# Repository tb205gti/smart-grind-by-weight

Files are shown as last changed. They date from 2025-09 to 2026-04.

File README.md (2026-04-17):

# Smart Grind-by-Weight

**Turn any grinder into a precision smart grind-by-weight system**

<table>
<tr>
<td width="50%">

https://github.com/user-attachments/assets/e20ce3e2-417e-4a3b-bb48-05591fce9418

</td>
<td width="50%">

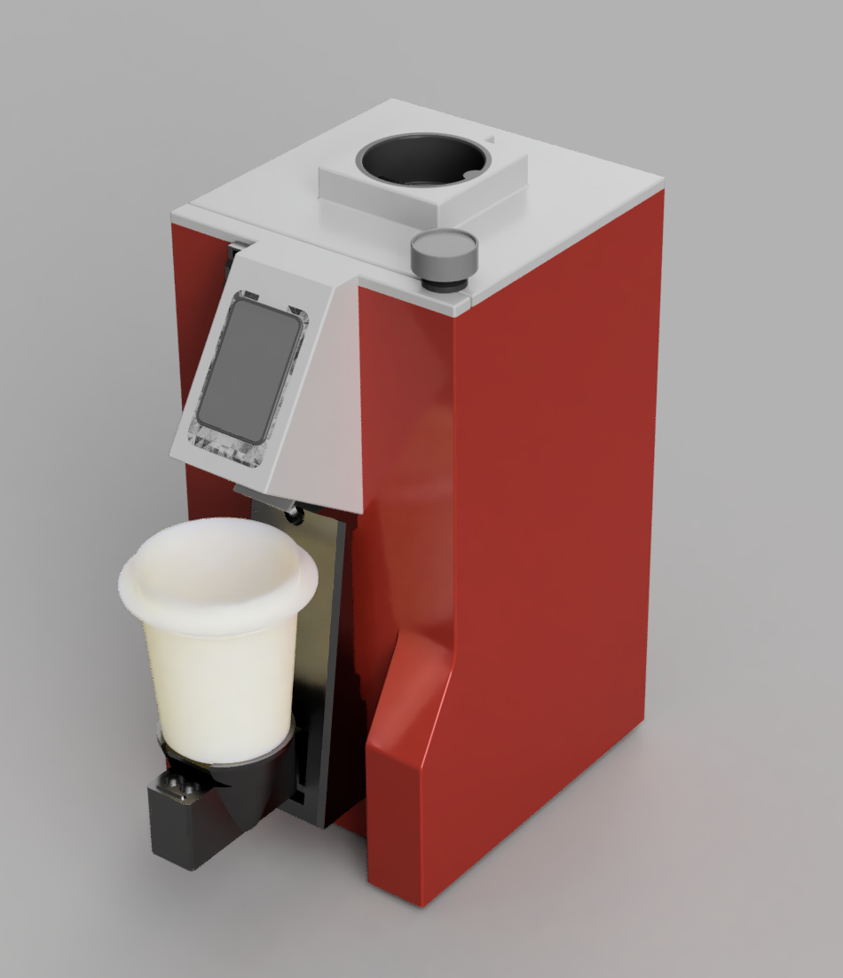
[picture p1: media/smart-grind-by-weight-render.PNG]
Smart Grind-by-Weight Modification
[](media/smart-grind-by-weight-render.PNG)

</td>
</tr>
</table>

> **⚠️ Newly Released Mod - Buyer Beware!**  
> This is a **recently released modification project** that transforms grinders into smart grind-by-weight systems. While functional and free/open source, it's should be considered an **experimental mod** that requires technical skill to build and may have rough edges. **Build at your own risk** !

The Smart Grind-by-Weight is a user-friendly, touch interface-driven, highly accurate open source grinder modification that can transforms any grinder (with a accesable motor relay) into an intelligent grind-by-weight system. Originally developed for the Eureka Mignon Specialita, the system can be easily adapted for other grinders.

**The concept is simple:** Perform a "brain swap" on your grinder. Replace the original controller with our intelligent ESP32-S3 controller and add a precision load cell to the mix.

**Upgrade cost:** €30-40 in parts  
**Target accuracy:** ±0.03g tolerance  
**No regrets**: No permanent modifications, and original grind-by-time mode is also available

---

## ✨ Features

- **User-friendly interface** with 3 profiles: Single, Double, Custom
- **Beautiful display** with simple graphics or detailed charts (easily switchable)
- **High accuracy**: ±0.03g error tolerance  
- **Zero-shot learning**: Algorithm adapts instantly to any grind size, bean setting, humidity etc. without manual tuning
- **Original timed run preserved** – there is a setting to enable the original Grind-By-Time mode
- **BLE OTA updates** for firmware
- **Advanced analytics** using BLE data transfer and Python Streamlit reports
- **For Eureka**: No permanent modifications needed - just swap the screen and add 3D printed parts

---

## 🧠 Intelligent Grinding Algorithm

Our predictive grinding system uses a zero-shot learning approach that adapts to any conditions:

```mermaid
flowchart LR
  start((Start Grind)) --> T[TARING]
  T --> E[PREDICTIVE<br/>learn latency & flow_rate<br/>compute motor_stop_target_weight]
  E --> S[SETTLING]
  S --> P[PULSE<br/>bounded pulse using effective_flow_rate]
  P -->|abs_error <= tolerance OR error < 0 OR pulses >= max| C[COMPLETED]
  P -->|needs more| S
```

**Key Innovation:** The algorithm learns grind latency and flow rate in real-time, then uses predictive control to stop just before the target weight, followed by precision pulses to reach exact accuracy. No manual tuning required.

---

## 🚀 Quick Start

### For Users - Using Pre-built Firmware

1. **Get the parts** - ESP32-S3 AMOLED display + HX711 + load cell (~€35 total) → See [Parts List](DOC.md#-parts-list)
2. **3D print the mounting parts** - All STL files included, no supports needed → See [3D Printed Parts](DOC.md#3d-printed-parts)
3. **Flash firmware & calibrate** - [Web Flasher](https://tb205gti.github.io/smart-grind-by-weight) (Chrome/Edge desktop + Android only) or command line
4. **Follow the assembly video** - [Complete Eureka build process](https://youtu.be/-kfKjiwJsGM)

**Ready to build?** → See **[DOC.md](docs/DOC.md)** for complete build instructions, parts list, and usage guide.

---

### For Developers - Building from Source

If you want to modify the code or contribute to development, see **[DEVELOPMENT.md](docs/DEVELOPMENT.md)** for build instructions.

**Design Files:** The complete Fusion 360 design is available at `3d_files/smart-grind-by-weight. Eureka Mignon.f3z` for modification and adaptation to other grinder models.

---

## 📊 Analytics Dashboard

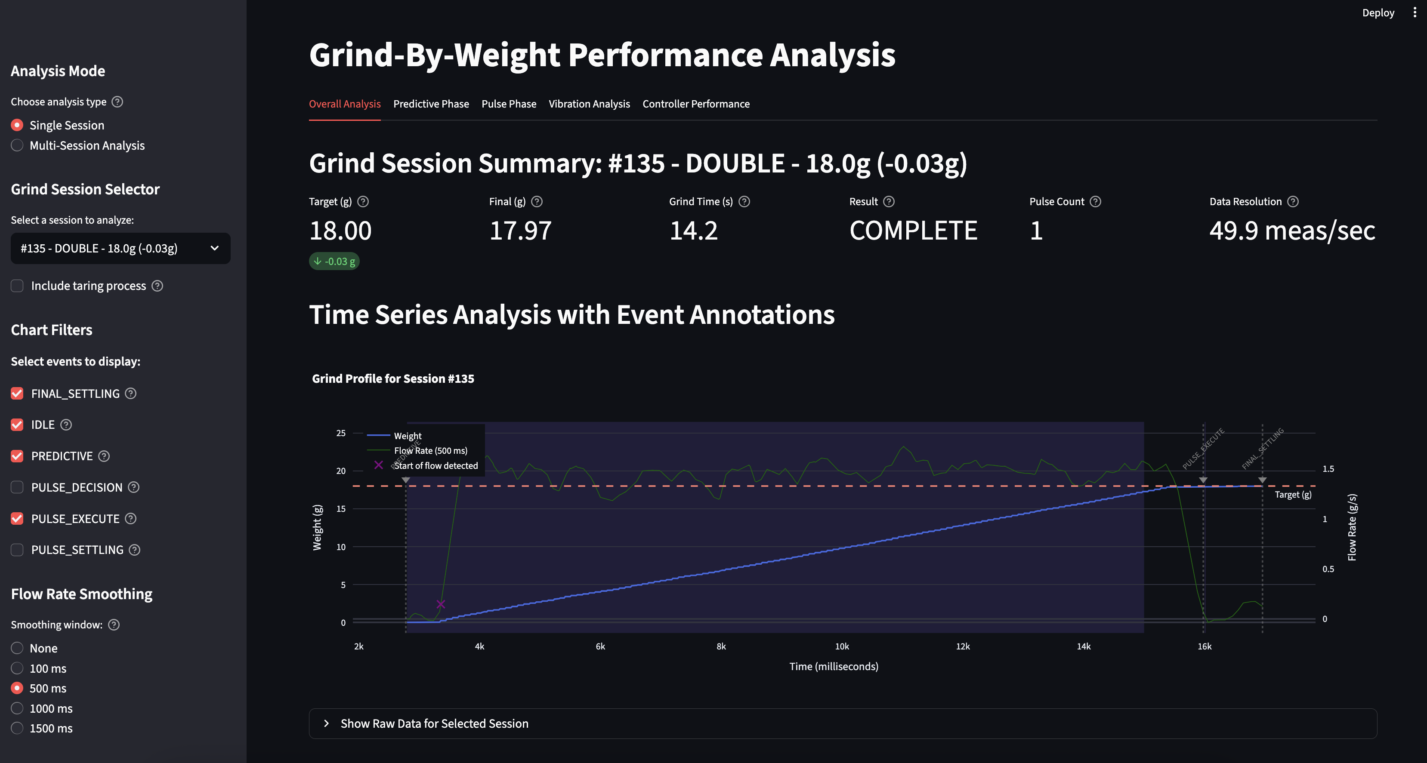
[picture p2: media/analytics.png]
Analytics Dashboard
[](media/analytics.png)

Export your grind data and analyze it with the included Streamlit dashboard:

```bash
python3 tools/grinder.py analyze
```

Track accuracy, flow rates, grind times, and optimize your coffee workflow with detailed session analytics.

---

## 🙏 Credits & Inspiration

This project was inspired by and builds upon the excellent work of:

- **[openGBW](https://github.com/jb-xyz/openGBW)** by jb-xyz - Open source grind-by-weight system
- **[Coffee Grinder Smart Scale](https://besson.co/projects/coffee-grinder-smart-scale)** by Besson - Smart scale integration concepts

---

## 📝 Personal Note

My goal with this project was to get real-life experience coding with AI agents. The code reflects that learning journey. I've learned a lot, and ultimately I'm in awe of how fast you can produce results with AI assistance. 

What I've learned so far is that "vibe coding" with AI is great for POCs and testing theories. But afterward you must pivot and reimplement features while keeping a close eye on the architecture the AI produces. Otherwise you'll get stuck at dead ends that require painful refactoring (been there, done that). 

In this project, that's most obvious when at state management - it's a bit cluttered in places. I'm very happy with the end result and I'm releasing the project as is. It eliminates grind weight variability from the espresso equation, bringing you one step closer to dialing in perfect shots.

**Project Status**: This project is shared 'as-is' and I have limited availability for support. While I'm happy to share what I've built, please understand that troubleshooting and feature requests may receive limited attention.

**Want to dive deeper?** → Check out **[DOC.md](docs/DOC.md)** for comprehensive documentation.

**Different grinder?** → See **[Grinder Compatibility Matrix](docs/GRINDER_COMPATIBILITY.md)** for adaptation guidance.

**Having issues?** → See **[TROUBLESHOOTING.md](docs/TROUBLESHOOTING.md)** for common problems and solutions.

**Changelog & Updates** → See **[Releases](https://github.com/tb205gti/smart-grind-by-weight/releases)** for version history and updates.

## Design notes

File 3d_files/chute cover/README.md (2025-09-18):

# Chute Cover Design - Abandoned/Legacy Approach

⚠️ **This design is abandoned and incomplete** ⚠️

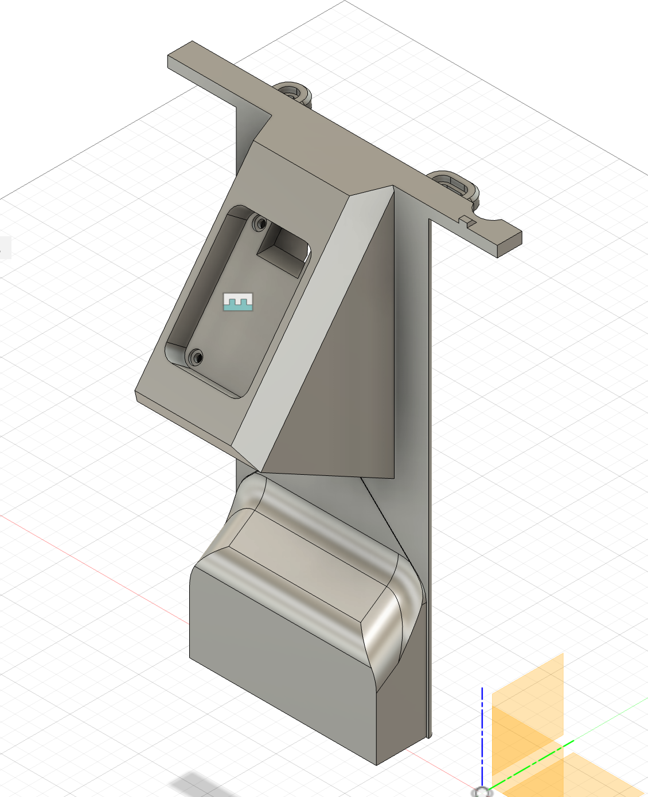
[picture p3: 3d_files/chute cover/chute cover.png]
Chute Cover 3D Design
[](chute cover.png)

## Overview

This folder contains an **abandoned 3D design** for a complete chute cover replacement that was originally intended to house the Waveshare ESP32-S3 AMOLED 1.64" display directly within the chute cover assembly.

## Why This Design Was Abandoned

The project has since **pivoted to a modular approach** using:
- Back plate (`Back plate.stl`)
- Waveshare adapter (`Waveshare AMOLED 1_64 adapter.stl`)
- Cover (`Cover.stl`)

This modular design is **easier to print**, **more reliable**, and **simpler to assemble**.

## Potential Use Cases

Despite being abandoned, this design can serve as an **excellent starting point** for adapting the Smart Grind-by-Weight modification to **other Eureka Mignon grinder models** that don't have an existing screen, such as:

- **Eureka Mignon Manuale**
- **Eureka Mignon Zero**
- **Eureka Mignon Silenzio**
- **Eureka Mignon Crono**

## ⚠️ Important Disclaimers

- **This design is NOT finished** and will require significant adjustments to work properly
- **No assembly instructions** are provided for this approach
- **Fit and finish issues** are likely and will need to be resolved
- **Use at your own risk** - this is experimental/prototype work

## Files Included

- `Eureka GBW - Eureka Chute Cover.f3z` - Fusion 360 source file
- `Chute cover.step` - Main chute cover STEP file
- `Chute Cover - Cover.step` - Cover component STEP file  
- `chute cover.png` - 3D render preview

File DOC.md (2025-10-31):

# Smart Grind-by-Weight Documentation

Complete build instructions, parts list, and usage guide for the Smart Grind-by-Weight system.

---

## 📋 Table of Contents

- [Parts List](#️-parts-list)
- [Assembly Video](#-assembly-video)
- [Installation & Wiring](#-installation--wiring)
- [Firmware Installation](#-firmware-installation)
- [Initial Calibration](#️-initial-calibration)
- [Usage Guide](#-usage-guide)
- [User Interface Navigation](#️-user-interface-navigation)
- [Bluetooth Connectivity](#-bluetooth-connectivity)
- [Diagnostic Report](#-diagnostic-report)
- [Analytics & Data Export](#-analytics--data-export)
- [Algorithm Details](#-algorithm-details)
- [Frequently Asked Questions](#-frequently-asked-questions)
- [Troubleshooting](#-troubleshooting)

---
## 🛠️ Parts List

> **Note:** All links are **for reference only** — sellers and items are **not personally verified** unless explicitly stated.

- **[Waveshare ESP32-S3 1.64" AMOLED Touch Display](https://www.waveshare.com/esp32-s3-touch-amoled-1.64.htm)** — Main controller
- **[HX711 ADC module](https://nl.aliexpress.com/item/1005006851380544.html)** — Load cell amplifier
- **MAVIN or T70 load cell** (0.3 – 1 kg range) — Weight sensor  
  ⚠️ Avoid cheap unshielded small load cells — accuracy will suffer
  - **1 kg:** Recommended. Suits portafilter use cases.
  - **0.3 kg:** Only suitable for dosing cups.
  - **Examples:**
    - [AliExpress T70](https://nl.aliexpress.com/item/1005009409460619.html)
    - [TinyTronics MAVIN](https://www.tinytronics.nl/en/sensors/weight-pressure-force/load-cells/mavin-load-cell-0.3kg)
    - [NA6 (Mavin) 0.3 / 1 kg](https://www.alibaba.com/product-detail/subject_1601564701384.html) - [NA6 that delivers to Germany](https://de.aliexpress.com/item/1005002600322988.html)
    - [T70 1 kg](https://nl.aliexpress.com/item/1005008658337192.html)
    - [P70 1 kg](https://nl.aliexpress.com/item/1005006257978435.html) (looks compatible with T70, not personally tested)
  - **Tested:** Only the 1 kg T70 and 0.3 kg Mavin load cells have been personally verified
- **6× M3 screws** (≈10 mm) — Mounting hardware
- **1000 µF capacitor** (10 V) — Power filtering [Example (untested)](https://nl.aliexpress.com/item/1005006037906723.html)
- **Wires & Dupont connectors** — General wiring  
  Example: [22 AWG silicone wire set](https://www.aliexpress.com/item/2255800441309579.html)
- **Dupont connector kit** — [Example (untested)](https://nl.aliexpress.com/item/1005008995345289.html)
- **Angled pin headers** — [Example (untested)](https://nl.aliexpress.com/item/1005006149080284.html)
- **[JST-PH 4-pin male connector (optional)](https://nl.aliexpress.com/item/1005009479983500.html)** — Optional solder-free connection to Eureka

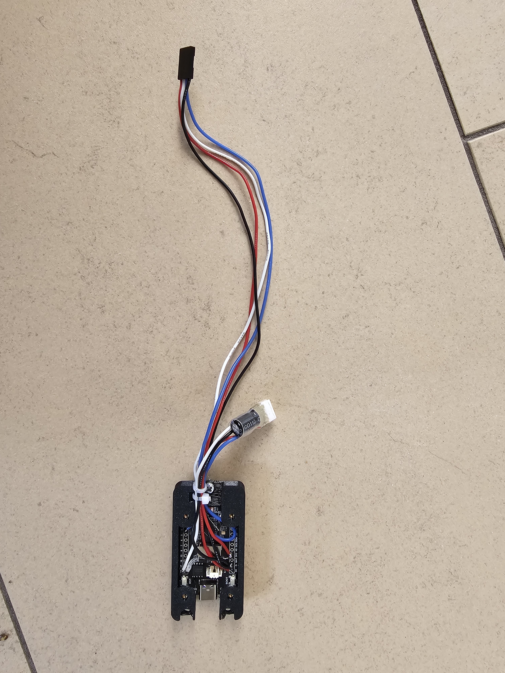
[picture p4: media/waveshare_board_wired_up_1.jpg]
Wired Waveshare Board
[](media/waveshare_board_wired_up_1.jpg)

### 3D Printed Parts

All parts designed to print **without supports**. Keep the orientation of the STL files. Some holes are covered with thin plastic layers that you can easily remove.

**Print Settings:**
- **Material**: PETG (preferred) - Flexible enough for snap fits to work properly
- **Layer Height**: 0.2mm
- **Alternative**: PLA might work but will offer a reduced experience due to brittleness

- **[Screen adapter](3d_files/Waveshare%20AMOLED%201_64%20adapter.stl)** - Mounts Waveshare screen to Eureka location
- **[Back plate](3d_files/Back%20plate.stl)** - Mounts to Eureka and holds HX711/load cell  
- **[Cover plate](3d_files/Cover.stl)** - Clean finishing cover
- **[Dosing cup holder](3d_files/Cup%20holder.stl)** - Connects to load cell for dosing cup
- **[Screw hole covers](3d_files/Cup%20holder%20hole%20cover.stl)** - Hides screws and protects against coffee grounds

### Fusion 360 Source Files
- **[All components](https://a360.co/3HYgubb)** - Customizable source files

Use these to adjust mounts for your specific grinder. Tuned for 54mm dosing cups. 
Compatible dosing cup: [AliExpress 54mm Cup](https://nl.aliexpress.com/item/1005006526852408.html)

---

## 📹 Assembly Video

Watch the complete Eureka Mignon Specialita assembly process: **[YouTube Assembly Guide](https://youtu.be/-kfKjiwJsGM)**

---

## 🔌 Installation & Wiring

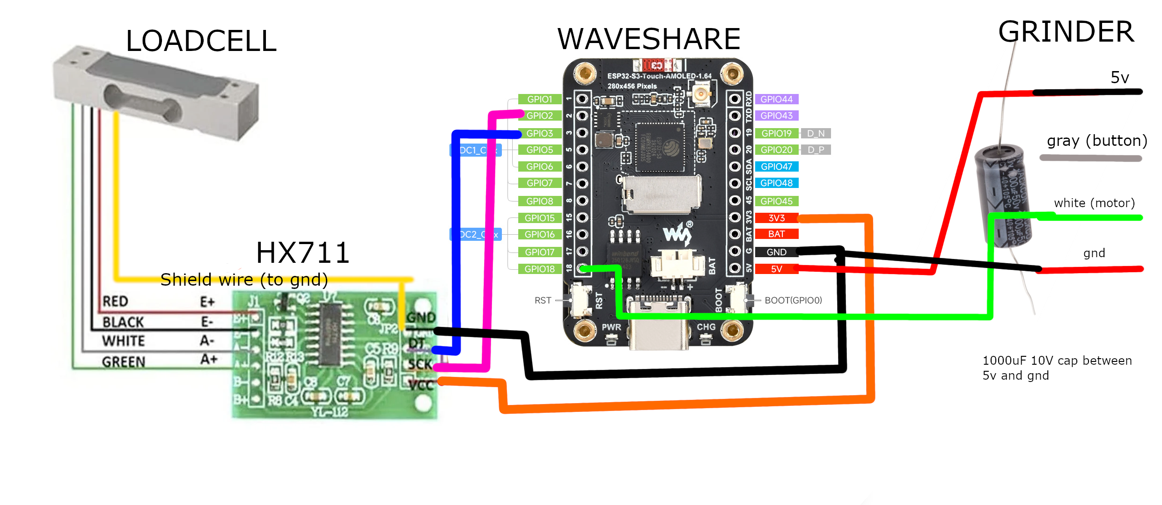
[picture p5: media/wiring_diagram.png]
Wiring Diagram
[](media/wiring_diagram.png)

### Pin Configuration

**HX711 Load Cell Amplifier Connections:**
```
ESP32-S3 GPIO 2    →    HX711 SCK
ESP32-S3 GPIO 3    →    HX711 DOUT
ESP32-S3 3.3V      →    HX711 VCC
ESP32-S3 GND       →    HX711 GND
```

**Load Cell to HX711 Wiring:**
```
Load Cell           HX711
Red (E+)         →  E+
Black (E-)       →  E-
White (A-)       →  A-
Green (A+)       →  A+
Yellow (Shield)  →  GND
```

- Connect the load cell shield wire (usually yellow) to the HX711 GND
- The HX711 only has 1 GND pin - solder the shield wire to the backside of the pin header
- **Tip**: Keep the load cell wire as short as possible to reduce noise

**Eureka Mignon Connections:**

⚠️ **CRITICAL WARNING:** Always verify your specific Eureka's wiring independently! Wire colors vary between units and cannot be trusted. Use the numbered pin positions shown in the reference image.

Using the 4-pin Eureka plug pinout (see `media/4-pin_Eureka_plug_pinout.png`), counting from left to right with the plug oriented with 'ribs' towards you:

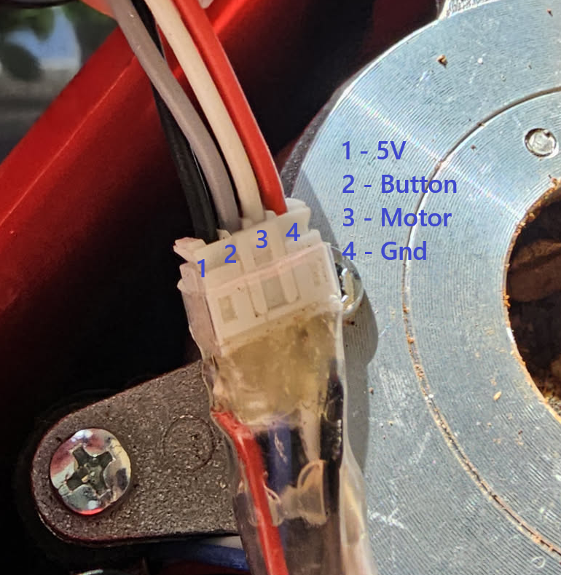
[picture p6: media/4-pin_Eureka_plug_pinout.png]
4-Pin Eureka Plug Pinout
[](media/4-pin_Eureka_plug_pinout.png)

```
ESP32-S3 5V        →    Pin 1 (5V power)
                        Pin 2 (Button signal - not used in this project)
ESP32-S3 GPIO 18   →    Pin 3 (Motor control signal)
ESP32-S3 GND       →    Pin 4 (Ground)
```

**4-Pin Eureka Plug Reference (Left to Right):**
- **Pin 1**: 5V power supply
- **Pin 2**: Button signal (unused in this project)  
- **Pin 3**: Motor control signal
- **Pin 4**: Ground

⚠️ **VERIFY 5V:** Use a multimeter to confirm 5V pin - wire colors vary between units! The Waveshare board has reverse polarity protection, and button/motor wires can be swapped without risk of damage.

### Installation Steps

1. **Flash the firmware** on the Waveshare board (see Firmware Instructions below)
2. **Add the 1000μF capacitor** between 5V and ground (protects against brownouts)
3. **Create HX711 to Waveshare connection:**
   - Add angled pin headers to HX711 (VCC, GND, DOUT, SCK pins)
   - Connect dupont cables to Waveshare board
   - Load cell can be directly soldered to HX711 (Make the wires as short as possible. Connect shield wire as well to GND)
4. **For Eureka Mignon assembly:**
   - Disassemble top plate and front plate
   - Remove the button and store it (not needed)
   - Use JST-PH plug to connect to Waveshare board
   - **WARNING:** Wire colors vary significantly between Eureka units - always verify pin functions with a multimeter before connecting!
   - Mount Waveshare screen using 3D printed adapter where original screen was (the Waveshare screen with adapter replaces the original screen and reuses the original mounting screws)
   - Fish HX711 wire through housing, exit via button hole
   - Mount load cell and HX711 to 3D printed back plate
   - Clip 3D printed back plate onto Eureka Mignon
   - Connect plug to HX711
   - Add 3D printed cover plate and screw down
   - Add 3D printed dosing cup holder on load cell and screw down
   - Hide screws with 3D printed screw covers
5. **Calibrate load cell** (see [Initial Calibration](#️-initial-calibration)) 

---

## 🚀 Firmware Installation

### 🌐 Web Flasher (Recommended)
**[🔗 Open Web Flasher Tool](https://jaapp.github.io/smart-grind-by-weight)**

**Browser Compatibility:**
- ✅ **Chrome** (Desktop & Android) - Full support
- ✅ **Microsoft Edge** (Desktop) - Full support
- ❌ **Safari/iOS** - Not supported (use command line method below)
- ❌ **Firefox** - Not supported (use command line method below)

**Two-Step Installation Process:**

1. **Initial Setup (USB - One Time Only)**
   - Connect ESP32 via USB cable
   - Use Chrome/Edge browser (desktop or Android)
   - Select firmware version from dropdown
   - Click "Flash via USB" - opens ESP Web Tools
   - After installation, device is ready for wireless updates

2. **Future Updates (BLE - After Installation)**
   - Power on the grinder and enable Bluetooth in device settings
   - Select firmware version from OTA dropdown
   - Click "Connect to Device" → "Flash Firmware"
   - Update happens wirelessly - **no USB cable needed**

**Key Benefits:**
- ✅ **No downloads needed** - firmware hosted automatically
- ✅ **No command line** - simple web interface
- ✅ **Automatic version listing** - all releases available in dropdown
- ✅ **Wireless updates** - once installed, never need USB again

*Initial USB flashing powered by [ESP Web Tools](https://esphome.github.io/esp-web-tools/)*

### Command Line (Fallback)
```bash
# First time (USB) - if web flasher unavailable
python3 tools/grinder.py upload smart-grind-by-weight-vX.X.X.bin

# Updates (BLE) - Enable device Bluetooth first  
python3 tools/grinder.py upload smart-grind-by-weight-vX.X.X.bin
```

**Manual firmware download:** [Releases page](https://github.com/jaapp/smart-grind-by-weight/releases)  
**Build from source:** See [DEVELOPMENT.md](DEVELOPMENT.md)

---

## ⚖️ Initial Calibration

After flashing firmware, calibrate the load cell for accurate measurements:

1. **Access calibration**: Menu → Calibrate (Tools section)
2. **Empty calibration**: Remove all weight from scale platform → Press OK
3. **Weight calibration**: 
   - Place known weight on scale (e.g., coffee mug with water)
   - Use +/- buttons to adjust displayed value to match actual weight
   - Press OK to complete

**Tip**: A coffee mug with water makes ideal calibration weight - weigh it on kitchen scale first.

### Auto-Tune Motor Response

The auto-tune feature models your grinder's motor response behavior by measuring the physical lag between relay activation and grounds production. This accounts for hardware variations like voltage differences (110V vs 220V), relay types (solid-state vs mechanical), and burr inertia across different grinder models. The default 50ms value works well for most setups, but if you experience unreliable pulse corrections or want to minimize coffee waste through hardware-specific optimization, run auto-tune via **Menu → Tune Pulses** (Tools section). The 1-2 minute calibration process finds the minimum reliable pulse duration for your specific hardware and saves it automatically.

### Diagnostics System

The system includes comprehensive load cell health monitoring accessible via **Menu → Diagnostics**. A warning icon (⚠) appears in the top-right corner when diagnostics are active - tap it to navigate directly to the diagnostics page.

**Diagnostic Types:**
1. **Load Cell Not Calibrated** - Appears until calibration is completed via Menu → Calibrate (Tools section)
2. **Sustained Noise** - Triggers after 60 seconds of excessive noise; clears after 120 seconds of acceptable levels
3. **Mechanical Instability** - Detects sudden weight drops during grinding (3+ events); auto-resets on next grind or via manual reset

**Displayed Values:**
- **Motor Latency** - Current motor response latency in milliseconds (default: 50ms, or calibrated value from auto-tune)
- **Calibration Factor** - Load cell calibration factor from Menu → Calibrate (Tools section)

**Noise Floor Diagnostics:**

Access via **Menu → Diagnostics → Noise Floor**.

**Three values displayed:**
1. **Standard Deviation (grams)** - Noise level in calibrated weight units
2. **Standard Deviation (ADC)** - Raw sensor noise values
3. **Noise Level Indicator** - Shows if noise will cause slow taring (>2s) or timeouts

**Important:** Noise diagnostics require prior calibration as they're based on calibrated gram values. High noise readings indicate wiring issues (check shield connection, use shorter wire leads). Read diagnostics in a stable, vibration-free environment for accurate assessment.

---

## 📱 Usage Guide

### Grinding Profiles
All profiles are fully customizable. Default grind-by-weight targets (fallback time values shown in parenthesis):
- **Single**: 9 g (5 s)
- **Double**: 18 g (10 s)  
- **Custom**: 21.5 g (12 s)

> 💡 **Tip** – the target label always shows the active unit (`g` or `s`). Long-press to edit in whichever mode you are currently using.

### Navigation
- **Swipe left/right** to navigate between menu tabs
- **Swipe up/down** on the ready screen to toggle between grind-by-weight and grind-by-time modes (when enabled in Menu → Grind Settings)
- **Tap** to select profiles or buttons
- **Long press** on profile targets to edit/customize them

> **Color cues:** The GRIND button background turns **red** in weight mode and **blue** in time mode, so you always know which behaviour is armed.

### Grind Settings
Access **Menu → Grind Settings** to configure:
- **Swipe Gestures**: Enable/disable vertical swipe gestures for mode switching (default: disabled)
- **Time Mode**: Directly toggle between Weight and Time modes regardless of swipe setting
- **Start on Cup**: Start the active profile automatically when the scale gains ≈50 g within ~2 s (after a short post-boot warmup)
- **Return on Removal**: Leave the completion screen as soon as that cup weight drops back off the scale
- **Purging** *(Advanced)*: Control how the grinder saturates itself before weight-mode grinding
  - **Prime mode**: Keeps the coffee used to saturate the grinder, continues immediately
  - **Purge mode** (default): Prompts you to discard stale grinds before continuing
  - **Amount slider**: Configure purge/prime amount (0.1g-5.0g, default 1.0g). Amount is a minimum target; actual output will be slightly higher.
  - **"Keep purge grinds from now on" checkbox**: Appears during purge confirmation - switches to Prime mode when checked

  *Explanation:* The time between motor start and grinds hitting the cup (grind latency) is used to predict the coast time (how long grinds will keep coming after the motor is disengaged). Purging clears stale coffee and saturates the grinder with fresh grounds, ensuring accurate latency detection. If you prefer to keep all coffee without manual intervention, select Prime mode.

### Basic Operation
These steps describe the default grind-by-weight workflow:
1. Select profile by tapping on the main screen
2. Long press the profile target to edit/customize the weight if needed
3. Place the dosing cup on the scale platform
4. Press the GRIND button – the scale will tare automatically
5. The system grinds to the precise target weight using the predictive algorithm
6. GRIND COMPLETE shows the final settled weight in grams (with statistics)

> Optional automation (Menu → Grind Settings): enable the new auto-start toggle to begin grinding as soon as the scale sees ~50 g arrive (no tare needed); the system waits for the load cell to gather enough quiet samples before arming itself, then auto-return jumps back to Ready whenever that cup is lifted off again.

Need the stock timed run? Enable swipe gestures in **Menu → Grind Settings**, then swipe up or down on the ready screen before you start; the GRIND button background turns blue to confirm time mode is active (red = weight). Alternatively, use the direct **Time Mode** toggle in the menu.

> **Time mode pulse button:** In time mode completion, a "+" button appears next to OK for 100ms additional grinding pulses.

### Quick Scale View
Need a simple live readout? Open **Menu → Scale** to jump into a full-screen weight display. Entering the page automatically tares the scale (using the same blocking overlay as the main workflow), and a large `TARE` button at the bottom lets you re-zero manually whenever you need.

### Display Modes
- **Arc Layout**: Clean, minimal arc-based interface
- **Nerdy Layout**: Detailed charts showing flow rates and real-time grinding analytics
- **Switching**: Tap anywhere on grind screen to switch between layouts during grinding

---

## 🗺️ User Interface Navigation

```
Main Screen (swipe left/right between tabs, up/down to toggle weight/time mode if enabled)
|
+-- Single Profile 
|   |-- Weight display (long press to edit)
|   \-- GRIND button (red=weight, blue=time)
|
+-- Double Profile
|   |-- Weight display (long press to edit)
|   \-- GRIND button (red=weight, blue=time)
|
+-- Custom Profile
|   |-- Weight display (long press to edit)
|   \-- GRIND button (red=weight, blue=time)
|   \-- Time mode completion: OK + PULSE buttons
|
\-- Menu (scrollable hub)
    |
    +-- Tools (quick actions)
    |   |-- Scale (live weight view with Tare action)
    |   |-- Calibrate (launch calibration workflow)
    |   |-- Tune Pulses (auto-tune motor latency)
    |   \-- Motor Test (1s safety pulse)
    |
    +-- Settings
    |   +-- Bluetooth
    |   |   |-- Bluetooth toggle (30m timer)
    |   |   |-- Bluetooth startup toggle (configurable auto-enable)
    |   |   |-- Connection status display
    |   |   \-- Auto-disable timer display
    |   |
    |   +-- Display
    |   |   |-- Normal brightness slider
    |   |   \-- Screensaver brightness slider
    |   |
    |   \-- Grind Settings
    |       |-- Swipe Gestures toggle (enable/disable vertical swipes)
    |       |-- Time Mode toggle (direct weight/time mode selection)
    |       |-- Start on Cup toggle (start when ≈50 g arrives within ~2 s)
    |       |-- Return on Removal toggle (drop back to Ready when that weight leaves)
    |       |-- Purging (Prime/Purge radio buttons)
    |       \-- Amount slider (0.1g-5.0g for purge/prime operation)
    |
    \-- Info
        +-- Diagnostics
        |   |-- Load Cell Status (calibration flag, calibration factor)
        |   |-- Noise Floor (std dev g/ADC, noise level indicator)
        |   |-- Active diagnostic warnings
        |   \-- Reset diagnostics button
        |
        +-- System Info
        |   |-- Firmware version & build number
        |   |-- Real-time weight sensor data (instant, samples, raw)
        |   |-- Uptime display
        |   \-- Memory usage
        |
        +-- Logs & Data
        |   |-- Logging toggle (enable/disable session file writing)
        |   |-- Sessions / Events / Measurements counters
        |   |-- Purge Logs button
        |   \-- Factory Reset button
        |
        \-- Lifetime Stats
            |-- Refresh Stats button
            |-- Total grinds, shots, weight
            |-- Motor runtime, uptime, accuracy
            \-- Pulse counts

During Grinding:
|-- Weight display & progress
|-- Tap anywhere: Arc ↔ Nerdy display modes
|-- STOP button
\-- Purge Confirmation (appears in Purge mode after grinder saturation)
    |-- "Grinder Purged" title
    |-- Instruction message
    |-- "Keep purge grinds from now on" checkbox
    \-- CONTINUE button
```

---

## ⚡ Automated Grind Flow

Want the scale to run itself? Enable the automation toggles in **Menu → Grind Settings**:

- **Start on Cup**: As soon as a recognized cup or portafilter lands on the load cell (≈50 g delta inside a 2 s window), the active profile tars and begins grinding automatically. Ideal when dosing cups dock directly under the chute.
- **Return on Removal**: When the cup weight drops away after completion, the grinder exits the results screen and returns to Ready. Useful for keeping the workflow hands-free between shots.

Both automation settings rely on the same smoothed weight deltas used for flow detection, so no extra calibration is required. Leave them disabled if you prefer manual control or experience false triggers with lighter accessories.

---

## 🔵 Bluetooth Connectivity

Bluetooth can be configured in **Menu → Bluetooth** with optional auto-startup (5-minute timer) or manual control (30-minute timer when manually enabled). The blue Bluetooth symbol in the top-right corner indicates when active. Bluetooth enables wireless firmware updates via BLE OTA, grind data export and analytics, and device management. Grind session logging is configurable in **Menu → Data → Logging** (disabled by default to prevent flash wear) and must be enabled before grinding to save session data for later analysis.

---

## 🔍 Diagnostic Report

Generate a comprehensive diagnostic report from your device for troubleshooting or attaching to GitHub issues. The report includes firmware version, system health metrics, load cell diagnostics, and all compile-time parameters.

### Report Contents

- **Firmware Information**: Version, build number, git commit, branch, and build timestamp
- **System Runtime**: Uptime, CPU frequency, heap memory usage, flash size, and driver type
- **Runtime Diagnostics**:
  - Load cell calibration status and factor
  - Noise levels (standard deviation in grams and ADC units)
  - Noise acceptability assessment
  - Motor response latency (default or auto-tuned value)
- **Compile-Time Parameters**: Profile defaults, weight/time ranges, screen settings, auto-grind thresholds, and all user-configurable constants

### Access Methods

**Web Flasher (Recommended):**
1. Visit the [Web Flasher Tool](https://jaapp.github.io/smart-grind-by-weight)
2. Navigate to the **Diagnostics** tab
3. Click "Connect & Get Diagnostics"
4. Copy to clipboard or download the report as a text file

**Command Line:**
```bash
# Display report in terminal
python3 tools/grinder.py diagnostics

# Save report to file
python3 tools/grinder.py diagnostics --save diagnostic-report.txt
```

**When to Use:**
- Reporting bugs or issues on GitHub (attach the report to your issue)
- Verifying calibration status and noise levels
- Checking motor latency settings after auto-tune
- Confirming firmware version and compile-time parameters
- General troubleshooting and system health assessment

---

## 📊 Analytics & Data Export

⚠️ **Important**: Grind session logging is **disabled by default** to prevent unnecessary flash wear. To analyze grind data:

1. **Enable logging** in **Menu → Data → Logging** before grinding
2. Perform your grind sessions (data will be saved to flash storage)
3. **Export and analyze** the data using the tools below
4. **Disable logging** again when analysis is complete (recommended for daily use)

### Launch Interactive Dashboard
```bash
# Export data and launch Streamlit dashboard
python3 tools/grinder.py analyze

# Or view reports from existing data
python3 tools/grinder.py report
```

### Available Tools
```bash
python3 tools/grinder.py --help          # Show all available commands
python3 tools/grinder.py scan            # Scan for BLE devices
python3 tools/grinder.py connect         # Connect to grinder device  
python3 tools/grinder.py debug           # Stream live debug logs
python3 tools/grinder.py info            # Get device system information
python3 tools/grinder.py export          # Export grind data to database
```

### Tools Directory Structure
- **`grinder.py`**: Cross-platform Python tool for all operations (build, upload, analyze)
- **`ble/`**: BLE communication tools and OTA update system
- **`streamlit-reports/`**: Interactive data visualization and analytics
- **`database/`**: SQLite database management for grind session storage

---

## 🧠 Algorithm Details

### Grinding Algorithm

The system uses a **zero-shot learning algorithm** requiring no prior knowledge or manually tuned variables. It instantly adapts to changes in temperature, humidity, grinding coarseness, bean type, and hardware characteristics.

**Multi-Phase Approach:**

1. **Initialization & Taring Phase**
   - Automatic tare on grind button press
   - 30-second timeout from grind start to completion
   - Noise-adaptive settling detection

2. **Grinder Saturation Phase** (Weight mode only)
   - Saturates the grinder before main grind for accurate latency detection
   - Configurable amount: 0.1g-5.0g (default 1.0g)
   - **Prime mode**: Keeps coffee, continues immediately after settling
   - **Purge mode**: Shows confirmation popup, waits for user to discard stale grinds
   - Logging and chart updates disabled during purge confirmation

3. **Predictive Phase**
   - Learns flow rate and motor-to-cup latency (relay + motor inertia + burr spin-up)
   - Predicts when to stop motor based on measured flow and coast characteristics
   - Target: barely undershoot target weight (overshoot is unrecoverable)
   - Uses runtime-configurable motor response latency (30-200ms, default 50ms)

4. **Pulse Correction Phase**
   - Conservative pulse duration calculation using 95th percentile flow rate
   - Bounded pulses respect hardware-specific motor response latency
   - Pulses range from motor latency minimum to latency + 225ms maximum
   - Mechanical instability detection (3+ sudden weight drops triggers diagnostic)
   - Repeats until target ± tolerance reached

5. **Time Mode Additional Pulses**
   - Dedicated `TIME_ADDITIONAL_PULSE` phase for post-completion grinding
   - 100ms fixed pulse duration
   - Split-button UI: OK + PULSE buttons on completion screen

**Motor Response Latency Model:**

The motor response latency represents the physical system lag between relay activation and grounds production. This value is hardware-specific and accounts for:
- Relay closure time (solid-state vs mechanical relays)
- Motor inertia (110V vs 220V motors)
- Burr spin-up characteristics (different grinder models/designs)

The latency value is automatically calibrated via **Auto-Tune Motor Response** (Menu → Tune Pulses) using binary search with statistical verification, or uses a safe 50ms default. This enables universal grinder compatibility without firmware modifications.

**Key Features:**
- Noise-resistant through multi-modal load cell measurement (instant, smoothed, filtered)
- Hardware-adaptive pulse control via runtime motor latency
- Conservative approach: undershoots target, then corrects with bounded pulses
- Mechanical instability detection with hysteresis and persistence
- 30-second grind timeout protection with user acknowledgment requirement

---

## ❓ Frequently Asked Questions

**Will this modification work on grinders other than the Eureka Mignon Specialita?**

See the comprehensive **[Grinder Compatibility Matrix](GRINDER_COMPATIBILITY.md)** for detailed compatibility information across different grinder models, including confirmed compatible models, adaptation requirements, and installation methods.

**Can I use this to grind directly into a portafilter instead of a dosing cup?**

Yes, but requires modifications: use 1kg load cell (vs 0.3kg) for better accuracy with heavier portafilters. Design and 3D print custom portafilter holder mounting to load cell. The dosing cup holder design serves as reference for portafilter adapter.

---

## 🔧 Troubleshooting

For common build and setup issues, see **[TROUBLESHOOTING.md](TROUBLESHOOTING.md)**.

---

For additional support, refer to the project repository issues section, but please note that support availability is limited as mentioned in the project status.

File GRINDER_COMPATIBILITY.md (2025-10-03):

# Grinder Compatibility Matrix

Compatibility guide for Smart Grind-by-Weight modification across grinder models. GBW (Grind-by-Weight) models excluded as they don't need this mod.

## Compatibility Overview

| Model | Status | Method | 3D Parts | Notes |
|---|---|---|---|---|
| [**Mignon Specialita**](https://www.eureka.co.it/en/products/eureka+1920/mignon+grinders/silent+range/20.aspx) | ✅ **100% Compatible** | Screen replacement | ✅ **Ready** | Tested, direct fit |
| [**Mignon XL**](https://www.eureka.co.it/en/products/eureka+oro/prosumer+grinders/prosumer/40.aspx) | ✅ **100% Compatible** | Screen replacement | ✅ **Ready** | Confirmed working |
| [**Mignon Silenzio**](https://www.eureka.co.it/en/products/eureka+1920/mignon+grinders/silent+range/19.aspx) | 🔧 **Pin soldering** | Custom mount + pins | 🛠️ **Needs design** | Timer pot, no screen |
| [**Mignon Crono**](https://www.eureka.co.it/en/products/eureka+1920/mignon+grinders/filter+range/26.aspx) | 🔧 **Pin soldering** | Custom mount + pins | 🛠️ **Needs design** | Timer pot, no screen |
| [**Mignon Manuale**](https://www.eureka.co.it/en/products/eureka+1920/mignon+grinders/evolution+range/27.aspx) | 🔧 **Pin soldering** | Custom mount + pins | 🛠️ **Needs design** | Timer pot, no screen |
| [**Mignon Zero**](https://www.eureka.co.it/en/products/eureka+1920/mignon+grinders/zero+range/74.aspx) | 🔧 **Extra hardware** | Custom mount + relay | 🛠️ **Needs design** | Requires 230V optocoupler relay (3.3V logic) + external USB power |
| [**Atom series**](https://www.eureka.co.it/en/products/eureka+1920/commercial+grinders/atom+range/8.aspx) | ❓ **Unknown** | Research needed | ❌ **None** | Internals unknown |
| **Baratza models** | 🔧 **Custom work** | Full adaptation | ❌ **None** | Electronics + mounting |
| **Niche Zero** | 🔧 **Custom work** | Full adaptation | ❌ **None** | Electronics + mounting |
| **Mazzer models** | 🔧 **Custom work** | Full adaptation | ❌ **None** | Electronics + mounting |

## Methods Explained

- **Screen replacement**: Replace existing screen with Waveshare adapter
- **Pin soldering**: Direct board connections ([Besson method](https://besson.co/projects/coffee-grinder-smart-scale)) + custom mount using [abandoned chute cover](3d_files/chute%20cover/) as starting point
- **Custom work**: Full electronics research + mechanical adaptation needed

## 3D Parts Status

- **✅ Ready**: Production files available, tested fit
- **🛠️ Needs design**: [Abandoned chute cover](3d_files/chute%20cover/) available as starting point - **PRs welcome!**
- **❌ None**: No existing design files

Pin soldering example  
*Pin connections for non-screen models. Credit: [Besson Coffee Grinder Smart Scale](https://besson.co/projects/coffee-grinder-smart-scale)*

## Requirements

**Universal**: ESP32-S3 AMOLED, HX711, load cell, 5V power, motor control signal  
**Pin soldering**: 2N3904 transistor for 3.3V→5V conversion  
**Custom mounting**: 3D printed parts, mechanical adaptation

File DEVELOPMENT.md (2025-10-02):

# Development Guide

This guide is for developers who want to build the Smart Grind-by-Weight firmware from source, contribute to the project, or modify the code for their own use.

**End users:** If you just want to use the device, download pre-built firmware from [Releases](https://github.com/jaapp/smart-grind-by-weight/releases) instead.

---

## 🛠️ Development Setup

### Prerequisites

- **Python 3.8+** with pip
- **Git** for version control
- **USB cable** for initial firmware flashing
- **Hardware** (ESP32-S3 board, HX711, load cell) for testing

### Initial Setup

1. **Clone the repository:**
   ```bash
   git clone https://github.com/jaapp/smart-grind-by-weight.git
   cd smart-grind-by-weight
   ```

2. **Install development dependencies:**
   ```bash
   python3 tools/grinder.py install
   ```

This automatically creates a virtual environment and installs all required dependencies including PlatformIO.

---

## 🔧 Build Targets

The project has three build targets:

### Production Target: `waveshare-esp32s3-touch-amoled-164`
- **Use case:** Real hardware with load cell and grinder connected
- **Hardware:** Full ESP32-S3 + HX711 + load cell + grinder motor relay
- **Features:** All functionality enabled
- **Optimizations:** `-Ofast` optimization level for performance

### Debug Target: `waveshare-esp32s3-touch-amoled-164-debug`
- **Use case:** Development and debugging with real hardware
- **Hardware:** Full ESP32-S3 + HX711 + load cell + grinder motor relay
- **Features:**
  - All functionality enabled
  - Debug symbols included
  - 2-second UI serial delay for easier debugging
  - Serial monitor filters to suppress harmless touch driver errors

### Mock/Development Target: `waveshare-esp32s3-touch-amoled-164-mock`
- **Use cases:**
  - Development without connected load cell or grinder
  - Testing with device installed in grinder without wasting beans or taxing the motor
- **Hardware:** Can run on just the ESP32-S3 Waveshare board (without HX711 or grinder) OR with full hardware installed
- **Features:**
  - Simulated load cell readings (green background indicates mock HX711 driver is active)
  - Mock grinder motor (visual indicator instead of relay activation)
  - Debug features enabled

**Mock mode benefits:**
- Develop UI changes without affecting the actual grinder
- Bring your waveshare board with you for coding and testing on the road :)
- Work on new features without hardware setup or bean waste
- Capture USB serial messages for debugging

---

## 🚀 Building & Flashing

### Development Platform

This project uses the **pioarduino ESP32 platform** (a community fork) instead of the standard Espressif ESP32 platform. This ensures proper support for the Waveshare ESP32-S3 AMOLED display.

**Platform Details:**
- **Platform**: [pioarduino/platform-espressif32](https://github.com/pioarduino/platform-espressif32) (stable release)
- **Framework**: Arduino ESP32 Core 3.x
- **Target**: ESP32-S3 with AMOLED touch display

The platform dependency is automatically handled by PlatformIO via the `platformio.ini` configuration.

### Build Commands

**Build production firmware:**
```bash
python3 tools/grinder.py build
```

**Build debug firmware:**
```bash
python3 tools/venv/bin/python -m platformio run -e waveshare-esp32s3-touch-amoled-164-debug
```

**Build mock/development firmware:**
```bash
python3 tools/venv/bin/python -m platformio run -e waveshare-esp32s3-touch-amoled-164-mock
```

**Clean build artifacts:**
```bash
python3 tools/grinder.py clean
```

### Initial USB Flashing

For the first-time setup or when BLE isn't working:

```bash
# Build and upload via USB (production)
python3 tools/grinder.py build
python3 tools/venv/bin/python -m platformio run --target upload -e waveshare-esp32s3-touch-amoled-164

# Or for debug target
python3 tools/venv/bin/python -m platformio run --target upload -e waveshare-esp32s3-touch-amoled-164-debug

# Or for mock target
python3 tools/venv/bin/python -m platformio run --target upload -e waveshare-esp32s3-touch-amoled-164-mock
```

### BLE OTA Updates (After Initial Setup)

Once the device is running and connected to Bluetooth:

```bash
# Build and upload wirelessly (production)
python3 tools/grinder.py build-upload

# Upload specific firmware file
python3 tools/grinder.py upload path/to/smart-grind-by-weight-vX.X.X.bin

# Force full firmware update (skip delta patching)
python3 tools/grinder.py build-upload --force-full

# Scan for BLE devices
python3 tools/grinder.py scan

# Get device system info
python3 tools/grinder.py info
```

---

## 📦 Release Process

For maintainers creating releases, see **[RELEASES.md](RELEASES.md)** for detailed release workflow documentation.

---

## 🐛 Debugging

### Serial Monitor

```bash
# Monitor serial output via PlatformIO
python3 tools/venv/bin/python -m platformio device monitor
```

### BLE Debug Monitoring

```bash
# Live debug monitoring via BLE
python3 tools/grinder.py debug
```

**⚠️ BLE Monitoring Limitations:**
- **Boot messages are missed** - BLE connection establishes after device boot
- **Kernel panics not captured** - System-level crashes bypass BLE and go directly to serial
- **Framework messages missing** - Low-level Arduino/ESP-IDF messages don't route through BLE
- **Best for application debug** - Primarily receives debug messages from the smart-grind-by-weight firmware itself

For complete debugging (including boot sequence and system messages), use USB serial monitoring.

---

## 📚 Additional Documentation

- **[DOC.md](DOC.md)** - Complete build instructions and parts list
- **[TROUBLESHOOTING.md](TROUBLESHOOTING.md)** - Common issues and solutions
- **[GRINDER_COMPATIBILITY.md](GRINDER_COMPATIBILITY.md)** - Adapting to different grinder models
- **[RELEASES.md](RELEASES.md)** - Release process and versioning

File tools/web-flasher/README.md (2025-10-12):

# Smart Grind By Weight - Web Flasher

A browser-based firmware flashing tool for the Smart Grind By Weight ESP32 coffee grinder.

## Features

### 🔌 Initial Setup (USB)
- First-time firmware installation via ESP Web Tools
- Uses Web Serial API for direct USB connection
- Perfect for factory setup or recovery
- Powered by [ESP Web Tools](https://esphome.github.io/esp-web-tools/) for browser-based flashing

### 📶 OTA Updates (Bluetooth)
- Over-the-air updates for installed grinders
- Web Bluetooth API for wireless connection
- Full firmware updates (no delta compression)
- Progress tracking and status updates

## Browser Support

- ✅ **Chrome** (Desktop & Android) - Full support
- ✅ **Microsoft Edge** (Desktop) - Full support  
- ❌ **Firefox** - No Web Bluetooth support
- ❌ **Safari/iOS** - No Web Bluetooth support

## Usage

### For Initial Setup
1. Open the web flasher in Chrome/Edge
2. Go to "Initial Setup (USB)" tab
3. Enter firmware URL from GitHub release
4. Click "Flash via USB" - opens ESP Web Tools
5. Connect device via USB and flash

### For OTA Updates
1. Ensure grinder is powered and BLE enabled
2. Go to "OTA Update (BLE)" tab  
3. Enter firmware URL from GitHub release
4. Click "Connect to Device"
5. Click "Flash Firmware" when connected

## Firmware Sources

The firmware list is pulled straight from GitHub Releases—no files are stored in this repo. If you need the exact asset mapping, see `DOC.md`.

## Technical Details

### BLE Services Used
- **OTA Service**: `12345678-1234-1234-1234-123456789abc`
- **Data Transfer**: `87654321-4321-4321-4321-cba987654321`
- **Control Commands**: `11111111-2222-3333-4444-555555555555`
- **Status Updates**: `aaaaaaaa-bbbb-cccc-dddd-eeeeeeeeeeee`

### Protocol
- Based on existing Python BLE implementation
- 512-byte chunks for firmware transfer
- Status notifications for progress tracking
- Command structure: START → DATA_CHUNKS → END

## Development

The web flasher is automatically deployed via GitHub Pages when pushed to main branch.

### Local Testing

**Quick Start (Recommended):**
```bash
# From the tools directory
python3 start-webflasher.py

# If port 8000 is busy, you'll be prompted to kill the process
# Use a custom port
python3 start-webflasher.py --port 3000
```

The script will automatically:
- Check if the port is available
- Prompt to kill any conflicting process
- Start the server and display the URL
- Handle cleanup on exit

**Manual Start:**
```bash
# Serve locally (required for Web Bluetooth HTTPS requirement)
python3 -m http.server 8000 --directory tools/web-flasher
# Open http://localhost:8000
```

**Note:** While the production site requires HTTPS for Web Bluetooth, `localhost` is an exception and works with plain HTTP.

## Security

- All communications use Web Bluetooth's built-in security
- Firmware is downloaded directly from GitHub releases
- No credentials or keys stored locally

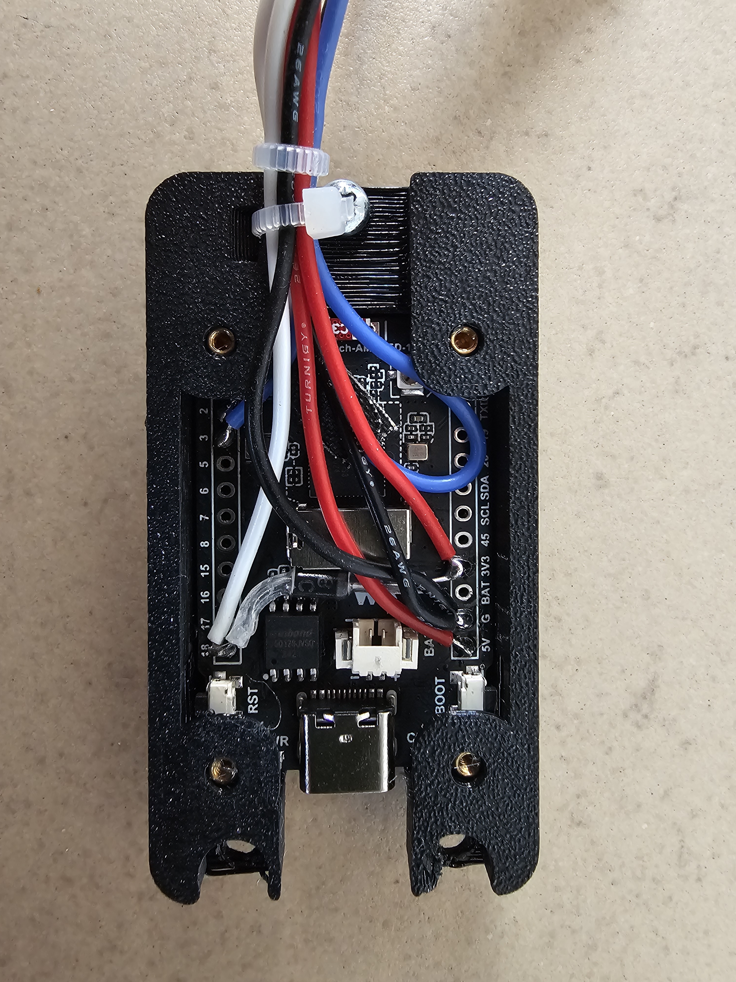
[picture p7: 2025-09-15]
media/waveshare_board_wired_up_2.jpg

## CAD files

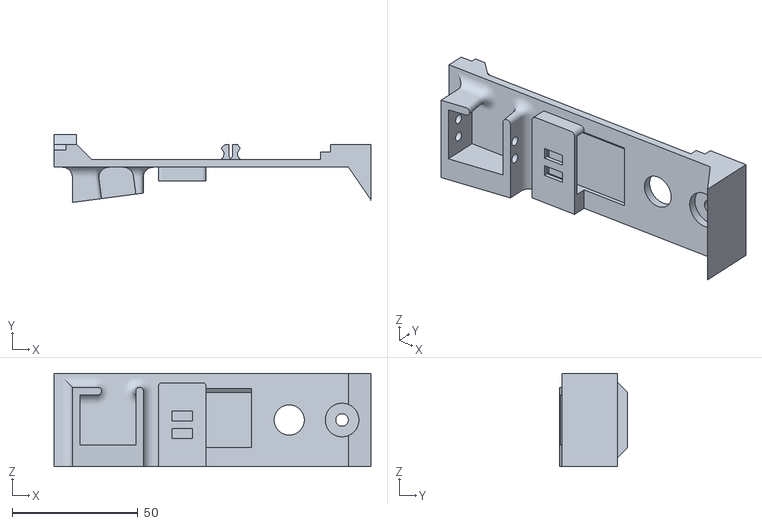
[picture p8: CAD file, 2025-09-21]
3d_files/Back plate.stl
126.0 x 27.0 x 37.0

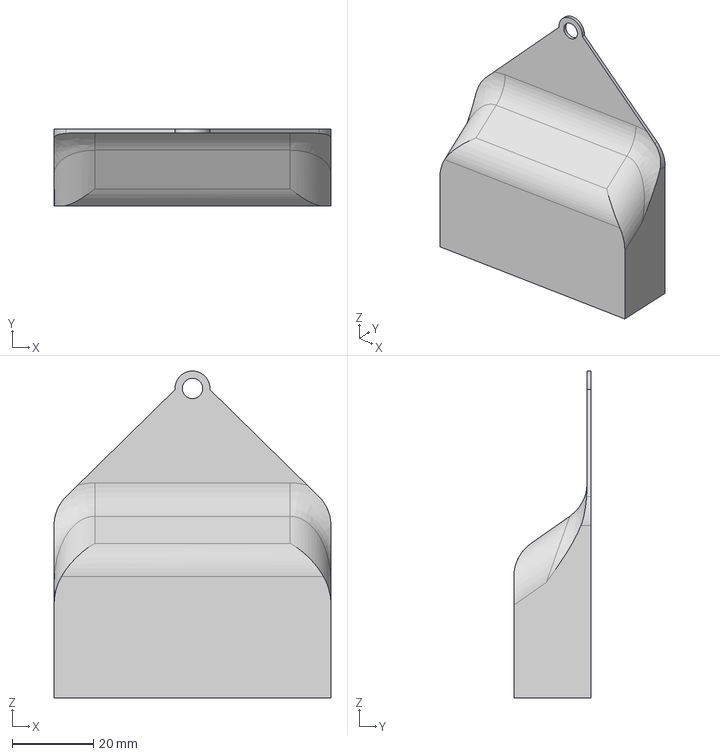
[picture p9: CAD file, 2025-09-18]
3d_files/chute cover/Chute Cover - Cover.step
68.0 x 19.0 x 80.3 mm

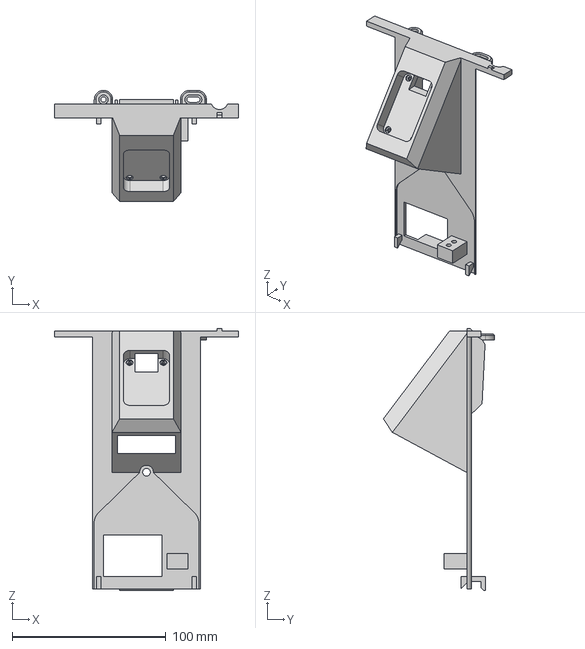
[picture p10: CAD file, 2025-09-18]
3d_files/chute cover/Chute cover.step
120.0 x 72.4 x 170.5 mm

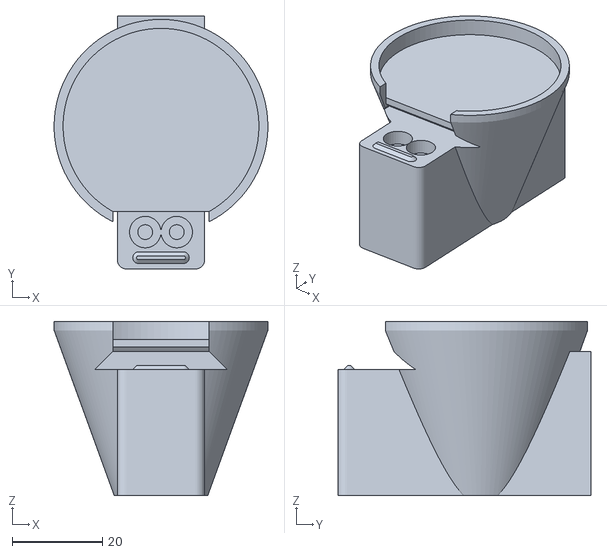
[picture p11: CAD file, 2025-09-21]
3d_files/Cup holder.stl
47.5 x 56.2 x 38.7

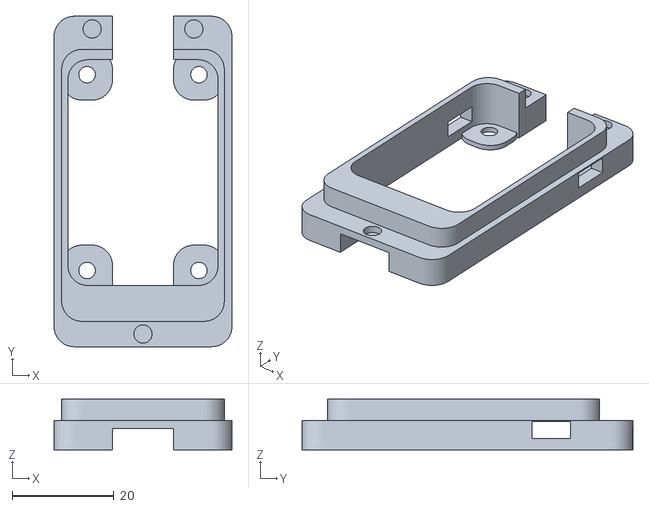
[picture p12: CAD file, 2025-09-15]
3d_files/Waveshare AMOLED 1_64 adapter.stl
35.0 x 65.0 x 10.0

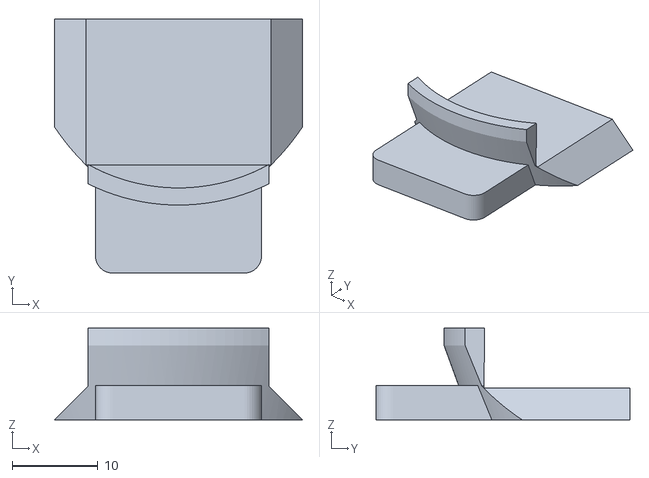
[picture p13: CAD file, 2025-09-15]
3d_files/Cup holder hole cover.stl
29.0 x 29.7 x 10.7

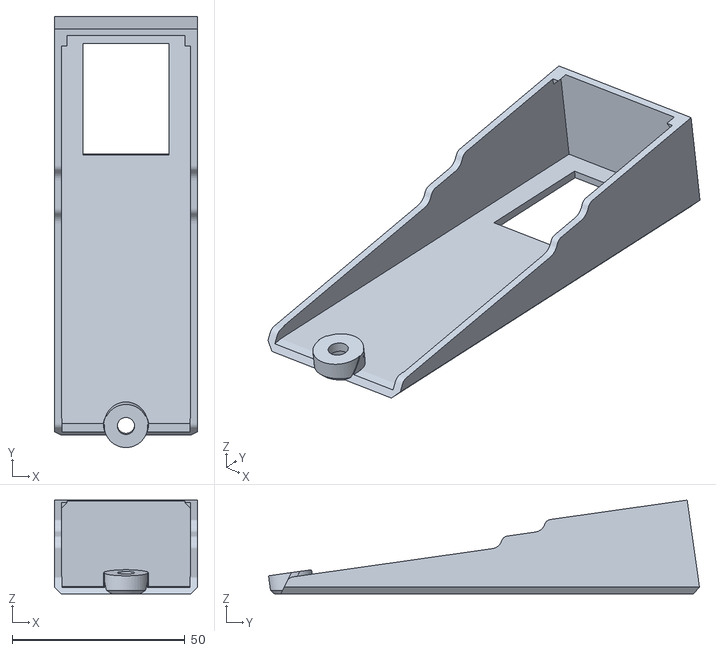
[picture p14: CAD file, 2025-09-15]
3d_files/Cover.stl
41.4 x 124.7 x 27.1

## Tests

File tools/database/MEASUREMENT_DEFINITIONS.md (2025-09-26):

# Grinder Measurement Definitions

This document provides comprehensive definitions for all measurements collected by the ESP32-S3 coffee grinder system. Each measurement includes its description, calculation method, and timestamp semantics.

**Source Reference**: Based on analysis of `src/controllers/grind_controller.cpp` and `src/logging/grind_logging.h`

---

## 1. GrindEvent Structure

**Purpose**: Discrete, low-frequency events summarising each major phase transition.  
**Frequency**: One event per phase entry.  
**Timestamp Semantics**: `timestamp_ms` marks the **start** of the phase relative to the session start.  
**Source**: `src/logging/grind_logging.h` / `src/controllers/grind_controller.cpp`

### Fields (LOG_SCHEMA_VERSION = 2)

#### `timestamp_ms` (uint32_t)
- Milliseconds since session start when this phase began.
- Captured as `millis() - session_start_time` at phase entry.

#### `duration_ms` (uint32_t)
- How long the phase remained active.
- `phase_end_time - phase_start_time`.

#### `grind_latency_ms` (uint32_t)
- Time from motor start until the controller detected flow.
- Populated for predictive phases to quantify burr spin-up latency.

#### `settling_duration_ms` (uint32_t)
- Mirrors `duration_ms` for settling-oriented phases to make postprocessing easier.
- Zero for phases where settling is not relevant.

#### `start_weight` / `end_weight` (float)
- Raw weight snapshot (grams) at entry/exit of the phase.
- Provides yield context per phase.

#### `motor_stop_target_weight` (float)
- Predicted motor cut-off weight (grams) calculated by the predictive algorithm.
- Snapshotted for every phase to trace adjustments over time.

#### `pulse_duration_ms` (float)
- Commanded pulse duration (milliseconds) during `PULSE_EXECUTE`.
- Zero for non-pulse phases.

#### `pulse_flow_rate` (float)
- Flow rate (g/s) carried forward from predictive phase for pulse calculations.
- Logged so downstream analytics can recompute expected yields.

#### `event_sequence_id` (uint16_t)
- Monotonic counter assigned by the logger (0-based).
- Guarantees deterministic ordering when exporting data.

#### `loop_count` (uint16_t)
- Number of control loop iterations executed while in this phase.
- Useful for verifying loop timing/performance.

#### `phase_id` (uint8_t)
- Encoded `GrindPhase` enum value at phase entry.
- See `src/controllers/grind_controller.h` for mapping.

#### `pulse_attempt_number` (uint8_t)
- 1-based pulse index (1..`USER_GRIND_MAX_PULSE_ATTEMPTS`).
- Zero for non-pulse phases.

#### `event_flags` (uint8_t)
- Bitmask metadata for quick filtering:  
  - `0x01` – Event recorded while running in grind-by-time mode.  
  - `0x02` – Phase kept the motor running (motor-active).  
  - `0x04` – Phase relates to the pulse subsystem (`PULSE_EXECUTE` / `PULSE_SETTLING`).
- Additional bits reserved for future analytics.

## 2. GrindMeasurement Structure

**Purpose**: High-frequency telemetry captured during grinding.  
**Frequency**: Logged every `SYS_LOG_EVERY_N_GRIND_LOOPS` iterations (default ≈100 ms).  
**Timestamp Semantics**: Actual time of the reading relative to session start.  
**Source**: `src/logging/grind_logging.h`

### Fields

#### `timestamp_ms` (uint32_t)
- Milliseconds since session start for this sample.
- Matches the controller loop timestamp.

#### `weight_grams` (float)
- Instantaneous cup weight (grams) read directly from the load cell fast-path.

#### `weight_delta` (float)
- Difference in grams compared to the previous logged measurement.
- Used to derive flow rate without recomputing on the host.

#### `flow_rate_g_per_s` (float)
- Instantaneous flow rate in grams/second calculated by the controller.
- Already filtered according to the active smoothing strategy.

#### `motor_stop_target_weight` (float)
- Current predictive motor stop target weight at the time of logging.
- Enables plotting how the target converges over time.

#### `sequence_id` (uint16_t)
- Monotonic measurement counter maintained by the logger (wraps at 65,535).
- Useful for gap detection when packets are dropped.

#### `motor_is_on` (uint8_t)
- Motor state snapshot (1 = running, 0 = stopped).
- Aligns with `GrindEvent` motor-active flags.

#### `phase_id` (uint8_t)
- Current controller phase when the sample was taken (`GrindPhase` enum).

## 3. GrindSession Structure

**Purpose**: Captures session-wide metadata, controller configuration, and results for both grind-by-weight and grind-by-time modes.  
**Frequency**: One record per session (stored alongside every event/measurement block).  
**Source**: `src/logging/grind_logging.h`

### Identity & Timing

- `session_id` (uint32_t) – Monotonic identifier persisted in preferences.  
- `session_timestamp` (uint32_t) – Start time in Unix seconds.  
- `target_time_ms` (uint32_t) – Requested grind duration for time-mode sessions (0 for weight mode).  
- `total_time_ms` (uint32_t) – Wall-clock duration from session start to completion.  
- `total_motor_on_time_ms` (uint32_t) – Sum of all motor active periods.  
- `time_error_ms` (int32_t) – `total_motor_on_time_ms - target_time_ms`; zeroed for weight mode.

### Weight Targets & Outcomes

- `target_weight` (float) – Desired cup weight (grams).  
- `tolerance` (float) – ± tolerance in grams captured at session start.  
- `start_weight` (float) – Pre-tare snapshot of cup weight (useful for scale drift analysis).  
- `final_weight` (float) – Settled weight recorded at session end.  
- `error_grams` (float) – `target_weight - final_weight`; explicitly set to `0.0f` for time-mode sessions to avoid misinterpretation.

### Mode, Status & Pulse Summary

- `profile_id` (uint8_t) – Active profile index (Single / Double / Custom).  
- `grind_mode` (uint8_t) – Encoded `GrindMode` enum (`0 = WEIGHT`, `1 = TIME`).  
- `max_pulse_attempts` (uint8_t) – Copy of `USER_GRIND_MAX_PULSE_ATTEMPTS`.  
- `pulse_count` (uint8_t) – Actual number of corrective pulses executed.  
- `termination_reason` (uint8_t) – Encoded `GrindTerminationReason` (COMPLETE / TIMEOUT / OVERSHOOT / MAX_PULSES / UNKNOWN).  
- `result_status` (char[16]) – Human-readable status string mirrored from the controller (e.g., `"COMPLETE"`, `"TIMEOUT"`, `"STOPPED_BY_USER"`).

### Predictive & Pulse Configuration Snapshots

- `initial_motor_stop_offset` (float) – Undershoot target used at session start.  
- `latency_to_coast_ratio` (float) – Ratio controlling coast compensation.  
- `flow_rate_threshold` (float) – Flow detection threshold (g/s).  
- `pulse_duration_large` / `medium` / `small` / `fine` (float) – Pulse timing lookup table (milliseconds).  
- `large_error_threshold` / `medium_error_threshold` / `small_error_threshold` (float) – Weight-error thresholds that classify undershoot severity.

## Key Calculation Details

### Dynamic Motor Stop Target Weight
```pseudocode
if (current_flow_rate >= USER_GRIND_FLOW_DETECTION_THRESHOLD_GPS && !flow_start_confirmed):
    grind_latency_ms = current_time - phase_start_time
    flow_start_confirmed = true
    
if (flow_start_confirmed && current_flow_rate > USER_GRIND_FLOW_DETECTION_THRESHOLD_GPS):
    motor_stop_target_weight = ((grind_latency_ms * USER_LATENCY_TO_COAST_RATIO) / 1000.0) * current_flow_rate
```

### Flow Rate (FlowRateData rolling window)
```pseudocode
// Used by GrindController for dynamic motor stop calculation
time_span_ms = newest_sample_time - oldest_sample_time
weight_span = newest_weight - oldest_weight
flow_rate = (weight_span / time_span_ms) * 1000.0
```

### Flow Rate (GrindLogger simple delta)
```pseudocode  
// Used by GrindMeasurement logging - pre-calculated by GrindController
flow_rate = weight_sensor->get_flow_rate()  // Passed as parameter
```

### Motor Time Tracking
```pseudocode
on_motor_start():
    motor_start_time = current_time
    
on_motor_stop():
    if motor_start_time > 0:
        total_motor_time += (current_time - motor_start_time)
```

---

## Important Notes

1. **Timestamp Semantics Differ**: 
   - GrindEvent timestamps = **phase start time**
   - GrindMeasurement timestamps = **measurement time**

2. **Error Sign Convention**: 
   - Positive error = undershoot (need more coffee)
   - Negative error = overshoot (too much coffee)
   - For grind-by-time sessions `error_grams` is explicitely zeroed; rely on `time_error_ms` instead.

3. **Two Flow Rate Methods**:
   - GrindController uses rolling window over 10 samples
   - GrindLogger uses simple delta between measurements

4. **Phase Duration vs Total Time**:
   - GrindEvent duration_ms = individual phase duration
   - GrindSession total_time_ms = entire session duration

5. **Motor Time vs Session Time**:
   - total_motor_on_time_ms = actual grinding time
   - total_time_ms = session duration (includes settling, etc.)

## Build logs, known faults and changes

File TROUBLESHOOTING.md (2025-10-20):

# Troubleshooting Guide

## Table of Contents

- [Motor Does Not Start](#motor-does-not-start)
- [HX711 Not Detected / Wrong Sample Rate](#hx711-not-detected--wrong-sample-rate)
- [Unknown board ID 'esp32-s3-devkitc-1'](#unknown-board-id-esp32-s3-devkitc-1)
- [PlatformIO Project Initialization Issues](#platformio-project-initialization-issues)
- [Grind Timeout Screen](#grind-timeout-screen)
- [Unreliable Pulse Corrections](#unreliable-pulse-corrections)
- [Getting Diagnostic Reports](#getting-diagnostic-reports)

---

## Motor Does Not Start

**Applies to:** Eureka Mignon installations where the grinder motor does not activate when commanded.

### Symptoms
- Motor test function (Menu → Motor Test) does not start the motor
- GRIND button does not start the motor
- All other functionality works normally (screen, weight readings, etc.)

**Note:** If you hear a click and humming sound but no coffee grounds come out, the motor **is** starting correctly - your grinder is clogged, not a wiring issue.

### Root Cause
The motor control wire (Pin 3) and button signal wire (Pin 2) from the Eureka 4-pin plug may be reversed on the Waveshare board connection. The button signal wire does not control the motor.

### Diagnosis

**Option 1: Use Motor Test Function (Recommended)**

Access **Menu → Motor Test** (Tools section) to verify motor connectivity. This button activates the motor for a short test pulse. If the motor does not run during the test, the motor wire is incorrectly connected.

**Option 2: Manual Wire Identification (Advanced - Use with Extreme Caution)**

⚠️ **DANGER:** This test involves live wires and can cause the grinder to start unexpectedly, potentially causing injury or damage. Only attempt if comfortable working with electrical systems.

Using the 4-pin Eureka plug pinout (see `media/4-pin_Eureka_plug_pinout.png` in documentation):
- **Pin 1**: 5V power supply
- **Pin 2**: Button signal (unused in this project)
- **Pin 3**: Motor control signal
- **Pin 4**: Ground

The motor control wire (Pin 3) is the wire that **starts the motor when briefly connected to ground (Pin 4)**. Test carefully:
1. Ensure grinder is powered and hopper has minimal beans
2. Disconnect the suspect wire from the Waveshare board
3. Briefly touch the wire to ground (Pin 4) - motor should start
4. **Be prepared for the powerful motor to cause the grinder to twist/jump**
5. **Avoid shorts that could damage the board or cause injury**

### Resolution

**Swap the wire connections:**
- The motor control wire (Pin 3) should connect to Waveshare **GPIO 18**
- The button signal wire (Pin 2) can remain disconnected (unused in this project)

If wires were reversed, swap them so Pin 3 connects to GPIO 18. The Waveshare board has reverse polarity protection for power connections, but the motor/button wires should be correctly identified for proper operation.

**Important:** Wire colors vary significantly between Eureka units - always refer to pin positions rather than wire colors when troubleshooting.

---

## HX711 Not Detected / Wrong Sample Rate

**Applies to:** First-boot issues when the load cell board is missing, miswired, or strapped for 80 SPS.

### Symptoms
- Startup log shows `HX711_NOT_CONNECTED` or `HX711_SAMPLE_RATE_INVALID`.
- Weight display stays at `0.00 g`; grinding and calibration remain disabled.

### Quick Fixes
- **NOT_CONNECTED:** Verify VCC/GND/SCK/DOUT wiring and that the HX711 board is powered.
- **SAMPLE_RATE_INVALID:** Ensure the HX711 `RATE` pin is tied to GND for 10 SPS; a floating/high pin forces 80 SPS and will now block startup.
- After correcting hardware, reboot the scale. The diagnostic clears automatically when healthy samples are detected.

## Unknown board ID 'esp32-s3-devkitc-1'

**Applies to:** Windows development environments using PlatformIO with ESP32-S3 boards.

### Symptoms
- `platformio run` fails with `UnknownBoard: Unknown board ID 'esp32-s3-devkitc-1'`.
- `pio boards espressif32 | findstr "esp32-s3"` shows the board, suggesting it exists in the registry.

### Root Cause
The local PlatformIO `espressif32` platform package was pinned to an older release (e.g. 3.1.0 from 2021) that predates ESP32-S3 board definitions. The registry lookup reports current boards, but the outdated local package lacks the corresponding JSON definition.

### Resolution
1. Update the global `espressif32` platform package so it includes ESP32-S3 board definitions:
   ```powershell
   C:\Users\<user>\.platformio\penv\Scripts\platformio.exe pkg install -g -p platformio/espressif32@^6.8.0
   ```
   *(Alternatively, run `pio platform update espressif32`.)*
2. Re-run the build:
   ```powershell
   C:\Users\<user>\.platformio\penv\Scripts\platformio.exe run
   ```
3. Optional: Pin the desired platform version in `platformio.ini` to ensure consistency across machines:
   ```ini
   [env:waveshare-esp32s3-touch-amoled-164]
   platform = platformio/espressif32@^6.8.0
   ```

### Notes
- The warning `Ignore unknown configuration option 'monitor_options'` also disappears once PlatformIO core and platform packages are current.
- If multiple PlatformIO installations are present, ensure you are updating the instance used for the project.

---

## PlatformIO Project Initialization Issues

**Applies to:** General PlatformIO project setup issues, especially when using PlatformIO (as this project uses the pioarduino fork as a platform).

### Symptoms
- `Error: Could not find one of 'package.json' manifest files in the package`
- PlatformIO fails to initialize the project properly
- Vague platform-related errors during project setup

### Root Cause
The use of the pioarduino platform fork can sometimes cause PlatformIO's cache or project state to become inconsistent, leading to initialization failures.

### Resolution
1. **Close VS Code completely**
2. **Delete the PlatformIO cache folder:**
   ```bash
   # On Windows
   rmdir /s "%USERPROFILE%\.platformio"
   
   # On macOS/Linux  
   rm -rf ~/.platformio
   ```
3. **Restart VS Code**
4. **Reopen the project** - PlatformIO will reinitialize and download the correct platform packages
5. **Perform a clean build** - Use PlatformIO's "Clean" then "Build" to ensure a fresh compilation

### Alternative (Less Nuclear)
If you want to try a less aggressive approach first:
1. Close VS Code
2. Delete only the platforms cache: `~/.platformio/platforms/` (or `%USERPROFILE%\.platformio\platforms\` on Windows)
3. Restart VS Code and reopen project
4. Perform a clean build in PlatformIO

**Note:** This issue is specific to the pioarduino platform fork usage and the way PlatformIO handles custom platform URLs.

---

## Grind Timeout Screen

**Applies to:** Grinder timing out during operation, showing timeout screen after 30 seconds.

### Symptoms
- Grinder reaches timeout screen during grinding cycle
- Long taring process (>10 seconds)
- Unstable weight readings

### Root Cause
Extended taring due to load cell noise prevents grinding from completing within 30-second limit.

### Diagnosis
Check **Menu → Diagnostics → "Noise Floor"** section (see [Diagnostics System](DOC.md#diagnostics-system) for details). If "Noise level: Too High" (red text) appears persistently, your load cell has sustained noise issues that will cause slow taring (>2 seconds). A warning icon (⚠) will appear in the top-right corner when sustained noise is detected.

### Resolution
1. **Check load cell wiring:**
   - Verify shielding wire connection per wiring diagram
   - Shorten load cell cables if possible
   - Ensure clean, solid connections

2. **Check calibration factor (reference examples only):**

   Calibration factors vary between individual load cells, but extreme deviations may indicate hardware issues. Check your calibration factor in **Menu → Diagnostics → Load Cell Status**. Example values from tested units:
   - **1KG T70 load cell**: ±4400 (example)
   - **0.3KG Mavin Load Cell**: ±6580 (example)

   **Note:** These are examples only and can differ significantly between load cells. Use them as rough reference points, not expected values.

3. **If wiring issues persist:**
   - Increase `GRIND_SCALE_SETTLING_TOLERANCE_G` parameter for more noise tolerance

---

## Unreliable Pulse Corrections

**Applies to:** Pulse corrections failing to produce grounds consistently, requiring multiple correction cycles.

### Symptoms
- Multiple pulse attempts needed to reach target weight
- Inconsistent grounds production during pulse phase
- Overshooting or undershooting target weight frequently

### Root Cause
Motor response latency mismatch between firmware settings and actual hardware characteristics. Default 50ms may not match your specific grinder's relay type (solid-state vs mechanical), voltage (110V vs 220V), or burr inertia.

### Resolution

**Recommended:** Use the Auto-Tune Motor Response feature to automatically calibrate optimal pulse duration for your hardware:

1. **Access auto-tune**: Menu → Tune Pulses (Tools section)
2. **Prepare system**:
   - Ensure beans are in hopper
   - Place dosing cup on scale
   - System will automatically tare
3. **Run calibration**: Process takes 1-2 minutes
   - Priming phase: 500ms pulse to position beans
   - Binary search: Finds minimum reliable pulse duration
   - Verification: Confirms 80%+ success rate across 5 test pulses
4. **Check result**: New motor latency value displayed on completion
   - Typical range: 30-200ms depending on hardware
   - Value saved automatically to device preferences
   - Displayed in **Menu → Diagnostics**

**Verify calibration**: Check **Menu → Diagnostics → Motor Latency** to see current value. Re-run auto-tune if you change grinders, modify relay hardware, or continue experiencing unreliable pulse corrections.

**Manual fallback:** If auto-tune fails, system reverts to safe 50ms default. Check grinder power connection, hopper bean level, and scale setup.

---

## Getting Diagnostic Reports

**Applies to:** Reporting issues on GitHub or troubleshooting system behavior.

### What is a Diagnostic Report?

The diagnostic report is a comprehensive text dump of your device's current state, including:
- Firmware version, build number, and git commit
- System information (uptime, CPU frequency, RAM, flash storage)
- All compile-time constants (grind settings, thresholds, timeouts)
- Runtime statistics (lifetime grinds, total weight)
- Load cell calibration status and noise diagnostics
- Motor latency settings
- Autotune results (if available)

This information helps identify configuration issues, hardware problems, or firmware bugs.

### How to Get a Diagnostic Report

#### Option 1: Web Flasher (Recommended)

1. Visit the **[Web Flasher Diagnostics Tool](https://jaapp.github.io/smart-grind-by-weight)**
2. Click the **"Diagnostics"** tab
3. Click **"Connect & Get Diagnostics"**
4. Select your device from the Bluetooth pairing dialog
5. Wait for the report to complete (~5-10 seconds)
6. Click **"Copy to Clipboard"** or **"Download Report"**
7. Paste the report into your GitHub issue

**Browser Requirements:** Chrome, Edge, or Opera on desktop/Android (Web Bluetooth API required)

#### Option 2: Command Line Tool

If you have the development environment set up:

```bash
# Get diagnostics and display in terminal
python3 tools/grinder.py diagnostics

# Save diagnostics to a file
python3 tools/grinder.py diagnostics --save diagnostics.txt
```

### When to Include a Diagnostic Report

**Always include a diagnostic report when reporting:**
- Grinding accuracy issues (overshooting/undershooting)
- Timeout errors or slow taring
- Load cell calibration problems
- Motor response issues
- Any unexpected behavior or crashes
- Feature requests that depend on your hardware configuration

**The diagnostic report is anonymous** and contains no personal information. It only includes technical device settings and statistics.

### Including Grind Results in Your Report

**For grind-related issues, follow these steps before generating the diagnostic report:**

1. **Enable logging:** Menu → Data → Enable Logging
2. **Reproduce the issue:** Perform at least one grind where the issue occurs
3. **Generate diagnostics:** Use one of the methods above (Web Flasher or Command Line)

The diagnostic report will automatically include your recent grind session data, which is essential for troubleshooting accuracy issues, pulse corrections, timeout problems, and other grind behavior issues. Without recent grind data, it's much harder to diagnose what's going wrong.

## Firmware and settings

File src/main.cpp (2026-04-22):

#include <Arduino.h>
#include <LittleFS.h>
#include <esp_system.h>
#include <esp_ota_ops.h>
#include "hardware/hardware_manager.h"
#include "system/state_machine.h"
#include "system/statistics_manager.h"
#include "controllers/profile_controller.h"
#include "controllers/grind_controller.h"
#include "ui/ui_manager.h"
#include "config/constants.h"
#include "bluetooth/manager.h"
#include "tasks/task_manager.h"
#include "tasks/weight_sampling_task.h"
#include "tasks/grind_control_task.h"
#include "tasks/file_io_task.h"

HardwareManager hardware_manager;
StateMachine state_machine;
ProfileController profile_controller;
GrindController grind_controller;
UIManager ui_manager;
BluetoothManager g_bluetooth_manager;
BluetoothManager& bluetooth_manager = g_bluetooth_manager;

#if SYS_ENABLE_REALTIME_HEARTBEAT
// Core 1 timing metrics (global scope for main loop access)
static uint32_t core1_cycle_count_10s = 0;
static uint32_t core1_cycle_time_sum_ms = 0;
static uint32_t core1_cycle_time_min_ms = UINT32_MAX;
static uint32_t core1_cycle_time_max_ms = 0;
static uint32_t core1_last_heartbeat_time = 0;
#endif

void setup() {
    Serial.begin(HW_SERIAL_BAUD_RATE);
#ifdef UI_DEBUG_SERIAL_DELAY_MS
    delay(UI_DEBUG_SERIAL_DELAY_MS);
#endif
    
    // Log reset reason to help diagnose unexpected resets/freeze scenarios
    esp_reset_reason_t rr = esp_reset_reason();
    const char* rr_str = "UNKNOWN";
    switch (rr) {
        case ESP_RST_POWERON: rr_str = "POWERON"; break;
        case ESP_RST_EXT: rr_str = "EXT (Reset Pin)"; break;
        case ESP_RST_SW: rr_str = "SW (esp_restart)"; break;
        case ESP_RST_PANIC: rr_str = "PANIC (Exception)"; break;
        case ESP_RST_INT_WDT: rr_str = "INT_WDT"; break;
        case ESP_RST_TASK_WDT: rr_str = "TASK_WDT"; break;
        case ESP_RST_WDT: rr_str = "WDT"; break;
        case ESP_RST_DEEPSLEEP: rr_str = "DEEPSLEEP"; break;
        case ESP_RST_BROWNOUT: rr_str = "BROWNOUT"; break;
        case ESP_RST_SDIO: rr_str = "SDIO"; break;
        default: break;
    }
    LOG_BLE("[STARTUP] Reset reason: %s (%d)\n", rr_str, rr);
    
    
    // Early startup heartbeat - helps capture initialization sequence
    LOG_BLE("[STARTUP] Initializing ESP32-S3 Coffee Scale - Build %d - Core1 active\n", BUILD_NUMBER);
    
    // Initialize LittleFS once - format if necessary
    if (!LittleFS.begin(true)) {
        LOG_BLE("ERROR: LittleFS mount failed - continuing without filesystem\n");
    } else {
        LOG_BLE("✅ LittleFS mounted successfully\n");
    }
    
    hardware_manager.init();
    hardware_manager.get_display()->set_brightness(USER_SCREEN_BRIGHTNESS_NORMAL);
    hardware_manager.get_display()->show_boot_splash();

    profile_controller.init(hardware_manager.get_preferences());
    statistics_manager.init(hardware_manager.get_preferences());
    grind_controller.init(hardware_manager.get_load_cell(), hardware_manager.get_grinder(), hardware_manager.get_preferences());
    
    // Set up the reference so HardwareManager can query GrindController state
    hardware_manager.set_grind_controller(&grind_controller);
    
    bluetooth_manager.init(hardware_manager.get_preferences());
    
    // Check for OTA failure to determine initial state
    String failed_ota_build = bluetooth_manager.check_ota_failure_after_boot();
    bool ota_failed = !failed_ota_build.isEmpty();

    // Check calibration status to determine initial screen
    bool is_calibrated = hardware_manager.get_weight_sensor()->is_calibrated();

    if (ota_failed) {
        LOG_BLE("BOOT: Starting in OTA failure state for expected build %s\n", failed_ota_build.c_str());
        state_machine.init(UIState::OTA_UPDATE_FAILED);
    } else if (!is_calibrated) {
        LOG_BLE("BOOT: Device not calibrated - starting in CALIBRATION state\n");
        state_machine.init(UIState::CALIBRATION);
    } else {
        state_machine.init(UIState::READY);
    }
    
    hardware_manager.get_display()->clear_boot_splash();
    ui_manager.init(&hardware_manager, &state_machine, &profile_controller, &grind_controller, &bluetooth_manager);
    
    // Store OTA failure info in ui_manager and refresh the screen so the
    // expected build/version text is populated (switch_to_state fires during
    // ui_manager.init() before set_failure_info() has been called, so we
    // need to call show_failure_screen() again with the data now available).
    if (ota_failed) {
        if (auto* ota = ui_manager.get_ota_data_export_controller()) {
            ota->set_failure_info(failed_ota_build.c_str());
            ota->show_failure_screen();
        }
    }
    
    // Set up UI status callback to avoid circular dependency
    bluetooth_manager.set_ui_status_callback([](const char* status) {
        if (auto* ota = ui_manager.get_ota_data_export_controller()) {
            ota->update_status(status);
        }
    });
    
    // Mark firmware as valid so the bootloader won't roll back on next crash.
    // Must be called after core systems are up; safe to call even when rollback
    // is not enabled (esp_ota_mark_app_valid_cancel_rollback is a no-op in that case).
    esp_ota_mark_app_valid_cancel_rollback();
    LOG_BLE("[STARTUP] Firmware marked as valid (rollback cancelled)\n");
    
    // Initialize individual task modules BEFORE TaskManager creates FreeRTOS tasks
    // This ensures all task dependencies are ready before tasks start running
    LOG_BLE("[STARTUP] Initializing task module dependencies...\n");
    weight_sampling_task.init(hardware_manager.get_load_cell(), &grind_logger);
    grind_control_task.init(&grind_controller, hardware_manager.get_load_cell(), 
                           hardware_manager.get_grinder(), &grind_logger);
    
    LOG_BLE("✅ Task module dependencies initialized\n");

    // Enable BLE by default during bootup with 2-minute timeout
    // (Previously disabled by default for security, now enabled for user convenience)
    LOG_BLE("Finally enabling BluetoothManager");
    bluetooth_manager.enable_during_bootup();

    // Initialize TaskManager with hardware and system interfaces
    LOG_BLE("[STARTUP] Initializing FreeRTOS Task Architecture...\n");
    bool task_init_success = task_manager.init(&hardware_manager, &state_machine, &profile_controller, 
                                              &grind_controller, &bluetooth_manager, &ui_manager);
    
    if (!task_init_success) {
        LOG_BLE("ERROR: Failed to initialize TaskManager - system cannot start\n");
        while (true) {
            delay(1000); // Halt system if task initialization fails
        }
    }
    
    LOG_BLE("✅ TaskManager initialized successfully\n");
    
    // Initialize remaining task modules that depend on TaskManager queues
    file_io_task.init(task_manager.get_file_io_queue());
    
    LOG_BLE("✅ All task modules initialized\n");
}

void loop() {


#if SYS_ENABLE_REALTIME_HEARTBEAT
    // Core 1 main loop timing (monitor main loop health)
    uint32_t cycle_start_time = millis();
    core1_cycle_count_10s++;
    if (core1_last_heartbeat_time == 0) core1_last_heartbeat_time = cycle_start_time;
#endif

    // Update device uptime statistics every 15 minutes, reporting back in hours
    static uint32_t last_uptime_update = 0;
    static uint32_t pending_uptime_minutes = 0;
    uint32_t current_time = millis();
    if (last_uptime_update == 0) {
        last_uptime_update = current_time;
    }
    constexpr uint32_t kUptimeIntervalMs = 900000; // 15 minutes
    constexpr uint32_t kUptimeIntervalMinutes = 15;
    uint32_t elapsed_ms = current_time - last_uptime_update;
    if (elapsed_ms >= kUptimeIntervalMs) {
        uint32_t intervals = elapsed_ms / kUptimeIntervalMs;
        pending_uptime_minutes += intervals * kUptimeIntervalMinutes;
        last_uptime_update += intervals * kUptimeIntervalMs;

        if (pending_uptime_minutes > 0) {
            statistics_manager.update_uptime(pending_uptime_minutes);
            pending_uptime_minutes = 0;
        }
    }
    
    // Check OTA state and suspend hardware tasks if needed
    static bool hardware_suspended = false;
    bool ota_active = bluetooth_manager.is_updating();
    
    if (ota_active && !hardware_suspended) {
        task_manager.suspend_hardware_tasks();
        hardware_suspended = true;
        LOG_BLE("[MAIN] Hardware tasks suspended for OTA\n");
    } else if (!ota_active && hardware_suspended) {
        task_manager.resume_hardware_tasks();
        hardware_suspended = false;
        LOG_BLE("[MAIN] Hardware tasks resumed after OTA\n");
    }
    
    // UI events are now processed inside the UI render FreeRTOS task
    // to serialize all LVGL updates on a single thread.
    
#if SYS_ENABLE_REALTIME_HEARTBEAT
    // Calculate Core 1 main loop timing
    uint32_t cycle_end_time = millis();
    uint32_t cycle_duration = cycle_end_time - cycle_start_time;
    core1_cycle_time_sum_ms += cycle_duration;
    if (cycle_duration < core1_cycle_time_min_ms) core1_cycle_time_min_ms = cycle_duration;
    if (cycle_duration > core1_cycle_time_max_ms) core1_cycle_time_max_ms = cycle_duration;
    
    // Core 1 Main Loop Heartbeat - Monitor main loop health (every 10 seconds)
    if (cycle_end_time - core1_last_heartbeat_time >= SYS_REALTIME_HEARTBEAT_INTERVAL_MS) {
        uint32_t avg_cycle_time = core1_cycle_count_10s > 0 ? core1_cycle_time_sum_ms / core1_cycle_count_10s : 0;
        
        // Get system states
        bool is_grinding = grind_controller.is_active();
        const char* ble_state = bluetooth_manager.is_enabled() ? 
                               (bluetooth_manager.is_connected() ? "CONN" : "ADV") : "OFF";
        const char* grinder_state = is_grinding ? "ACTIVE" : "IDLE";
        const char* tasks_status = task_manager.are_tasks_healthy() ? "HEALTHY" : "ERROR";
        size_t free_heap_kb = ESP.getFreeHeap() / 1024;

        LOG_BLE("[%lums MAIN_LOOP_HEARTBEAT] Cycles: %lu/10s | Avg: %lums (%lu-%lums) | Tasks: %s | BLE: %s | Grinder: %s | Mem: %zuKB | Build: #%d\n",
               millis(), core1_cycle_count_10s, avg_cycle_time, core1_cycle_time_min_ms, core1_cycle_time_max_ms,
               tasks_status, ble_state, grinder_state, free_heap_kb, BUILD_NUMBER);
        
        // Reset Core 1 metrics for next interval
        core1_cycle_count_10s = 0;
        core1_cycle_time_sum_ms = 0;
        core1_cycle_time_min_ms = UINT32_MAX;
        core1_cycle_time_max_ms = 0;
        core1_last_heartbeat_time = cycle_end_time;
    }
#endif
    
    // The main loop now runs much lighter since FreeRTOS tasks handle all the heavy work
    // Just yield to allow FreeRTOS scheduler to run other tasks efficiently
    vTaskDelay(pdMS_TO_TICKS(10)); // Small delay to prevent starving other tasks
}

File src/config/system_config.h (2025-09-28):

#pragma once

//==============================================================================
// SYSTEM CONFIGURATION CONSTANTS
//==============================================================================
// This file contains core system configuration values that control the
// operation of the ESP32 coffee grinder's internal algorithms and timing.
// These parameters affect system behavior, task scheduling, and algorithmic
// calculations.
//
// Categories:
// - Task Scheduling Intervals (RTOS task update frequencies)
// - Algorithm Parameters (error thresholds, calculation factors)
// - System Timeouts (operation limits, safety timeouts)
// - Display Processing (filtering, formatting, update rates)
// - Logging and Debug Configuration (output intervals, buffer sizes)
//
// All constants use the SYS_ prefix to indicate system-level parameters.

// Logging system is included separately where needed

//------------------------------------------------------------------------------
// FREERTOS TASK CONFIGURATION
//------------------------------------------------------------------------------
// Critical timing for FreeRTOS task architecture with 6 specialized tasks

// Task Intervals (milliseconds)
#define SYS_TASK_WEIGHT_SAMPLING_INTERVAL_MS 20                                // Weight sampling poll interval (50Hz poll; HX711 @10SPS) - Core 0
#define SYS_TASK_GRIND_CONTROL_INTERVAL_MS 20                                  // Grind controller update interval (50Hz) - Core 0
#define SYS_TASK_UI_INTERVAL_MS 16                                             // UI rendering frequency (60Hz) - Core 1  
#define SYS_TASK_BLUETOOTH_INTERVAL_MS 20                                      // Bluetooth handling frequency (50Hz) - Core 1
#define SYS_TASK_FILE_IO_INTERVAL_MS 100                                       // File I/O operations frequency (10Hz) - Core 1

// Task Stack Sizes (bytes) - Increased for BLE_LOG overhead and complex operations
#define SYS_TASK_WEIGHT_SAMPLING_STACK_SIZE 4096                               // 4KB stack for weight sampling (was 2KB, increased for BLE_LOG)
#define SYS_TASK_GRIND_CONTROL_STACK_SIZE 6144                                 // 6KB stack for grind control logic (was 4KB, increased for complex algorithms)
#define SYS_TASK_UI_STACK_SIZE 8192                                            // 8KB stack for LVGL rendering (unchanged)
#define SYS_TASK_BLUETOOTH_STACK_SIZE 4096                                     // 4KB stack for BLE operations (unchanged)
#define SYS_TASK_FILE_IO_STACK_SIZE 6144                                       // 6KB stack for LittleFS operations (was 4KB, increased for file operations)

// Task Priorities (higher number = higher priority)
#define SYS_TASK_PRIORITY_WEIGHT_SAMPLING 4                                    // Highest priority (real-time sampling)
#define SYS_TASK_PRIORITY_GRIND_CONTROL 3                                      // High priority (grind control)
#define SYS_TASK_PRIORITY_UI 2                                                 // Medium priority (UI updates)
// Raise BLE above UI to prevent starvation during transfers
#define SYS_TASK_PRIORITY_BLUETOOTH 3                                          // Higher priority (BLE operations)
#define SYS_TASK_PRIORITY_FILE_IO 1                                            // Low priority (file operations)

// Inter-Task Communication Queue Sizes
#define SYS_QUEUE_UI_TO_GRIND_SIZE 5                                           // UI events to grind controller
#define SYS_QUEUE_FILE_IO_SIZE 20                                              // File I/O operation requests

// Legacy task scheduler intervals (deprecated - kept for compatibility)
#define SYS_TASK_LOADCELL_INTERVAL_MS 20                                       // Load cell polling frequency (50Hz)

//------------------------------------------------------------------------------
// SYSTEM TIMEOUTS
//------------------------------------------------------------------------------
#define SYS_TIMEOUT_SHORT_MS 1000                                              // General short timeout for quick operations
#define SYS_TIMEOUT_MEDIUM_MS 2000                                             // Medium timeout for moderate operations  
#define SYS_TIMEOUT_LONG_MS 3000                                               // Long timeout for settling operations
#define SYS_TIMEOUT_EXTENDED_MS 5000                                           // Extended timeout for complex operations

//------------------------------------------------------------------------------
// TIME CONVERSION CONSTANTS
//------------------------------------------------------------------------------
#define SYS_MS_PER_SECOND 1000                                                 // Milliseconds per second conversion
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

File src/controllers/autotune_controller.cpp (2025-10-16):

#include "autotune_controller.h"
#include <Arduino.h>
#include <cmath>
#include <cstring>
#include <cstdarg>

#if defined(DEBUG_ENABLE_LOADCELL_MOCK) && (DEBUG_ENABLE_LOADCELL_MOCK != 0)
#include "../hardware/mock_hx711_driver.h"
#endif

AutoTuneController::AutoTuneController()
    : weight_sensor(nullptr)
    , grinder(nullptr)
    , grind_controller(nullptr)
    , current_phase(AutoTunePhase::IDLE)
    , sub_phase(AutoTuneSubPhase::IDLE)
    , is_running(false)
    , cancel_requested(false)
    , current_pulse_ms(0.0f)
    , active_pulse_ms(0.0f)
    , last_executed_pulse_ms(0.0f)
    , step_size(0.0f)
    , last_success_ms(0.0f)
    , direction(DOWN)
    , found_lower_bound(false)
    , iteration(0)
    , verification_round(0)
    , verification_pulse_count(0)
    , verification_success_count(0)
    , candidate_ms(0.0f)
    , last_settled_weight(0.0f)
    , pre_pulse_weight(0.0f)
    , phase_start_time(0)
    , settling_start_time(0)
{
    result.success = false;
    result.latency_ms = 0.0f;
    result.error_message = nullptr;

    memset(&progress, 0, sizeof(progress));
    progress.phase = AutoTunePhase::IDLE;
    progress.has_new_message = false;
}

void AutoTuneController::init(WeightSensor* ws, Grinder* gr, GrindController* gc) {
    weight_sensor = ws;
    grinder = gr;
    grind_controller = gc;
}

bool AutoTuneController::start() {
    if (!weight_sensor || !grinder || !grind_controller) {
        LOG_BLE("ERROR: AutoTune cannot start - missing hardware references\n");
        return false;
    }

    if (is_running) {
        LOG_BLE("WARNING: AutoTune already running\n");
        return false;
    }

    LOG_BLE("=== Starting Motor Response Latency Auto-Tune (Non-Blocking) ===\n");

    memset(&progress, 0, sizeof(progress));
    progress.phase = AutoTunePhase::IDLE;
    progress.has_new_message = false;

    is_running = true;
    cancel_requested = false;

    // Initialize binary search state
    current_pulse_ms = GRIND_AUTOTUNE_LATENCY_MAX_MS;
    step_size = GRIND_AUTOTUNE_LATENCY_MAX_MS - GRIND_AUTOTUNE_LATENCY_MIN_MS;
    last_success_ms = 0.0f;
    direction = DOWN;
    found_lower_bound = false;
    iteration = 0;
    active_pulse_ms = 0.0f;
    last_executed_pulse_ms = 0.0f;

    // Initialize verification state
    verification_round = 0;
    verification_pulse_count = 0;
    verification_success_count = 0;
    candidate_ms = 0.0f;

    // Store previous latency for comparison
    progress.previous_latency_ms = grind_controller->get_motor_response_latency();

    // Initialize autotune log file
    LittleFS.remove("/autotune.log");
    autotune_log_file = LittleFS.open("/autotune.log", "w");
    if (autotune_log_file) {
        autotune_log_file.println("=== Autotune Started ===");
        autotune_log_file.printf("Timestamp: %lums\n", millis());
        autotune_log_file.printf("Previous Latency: %.1fms\n", progress.previous_latency_ms);
        autotune_log_file.println();
        autotune_log_file.flush();
        LOG_BLE("AutoTune: Log file created at /autotune.log\n");
    } else {
        LOG_BLE("WARNING: AutoTune could not create log file (filesystem unavailable)\n");
    }

    // Start with priming phase
    switch_phase(AutoTunePhase::PRIMING);

    return true;
}

void AutoTuneController::cancel() {
    LOG_BLE("AutoTune: User cancel requested\n");
    cancel_requested = true;
}

void AutoTuneController::update() {
    if (!is_running) {
        return;
    }

    if (cancel_requested) {
        LOG_BLE("AutoTune: Cancelled by user\n");
        complete_with_failure("Cancelled by user");
        return;
    }

    switch (current_phase) {
        case AutoTunePhase::PRIMING:
            update_priming_phase();
            break;

        case AutoTunePhase::BINARY_SEARCH:
            update_binary_search_phase();
            break;

        case AutoTunePhase::VERIFICATION:
            update_verification_phase();
            break;

        case AutoTunePhase::COMPLETE_SUCCESS:
        case AutoTunePhase::COMPLETE_FAILURE:
        case AutoTunePhase::IDLE:
            // Terminal states - do nothing
            break;
    }
}

//==============================================================================
// Phase State Machines (Non-Blocking)
//==============================================================================

void AutoTuneController::update_priming_phase() {
    switch (sub_phase) {
        case AutoTuneSubPhase::IDLE:
            // Capture pre-prime weight for verification
            pre_pulse_weight = weight_sensor->get_weight_high_latency();
            LOG_BLE("AutoTune Phase 0: Priming chute with %dms pulse (pre-weight: %.3fg)\n",
                    GRIND_AUTOTUNE_PRIMING_PULSE_MS, pre_pulse_weight);
            log_message("Priming...");
            start_pulse(GRIND_AUTOTUNE_PRIMING_PULSE_MS);
            break;

        case AutoTuneSubPhase::PULSE_EXECUTE:
            update_pulse_execute();
            break;

        case AutoTuneSubPhase::MOTOR_SETTLING:
            update_motor_settling();
            break;

        case AutoTuneSubPhase::COLLECTION_DELAY:
            update_collection_delay();
            break;

        case AutoTuneSubPhase::SCALE_SETTLING:
            update_scale_settling();
            break;

        case AutoTuneSubPhase::MEASURE_COMPLETE: {
            // Verify that priming produced grounds
            float settled_weight = last_settled_weight;
            float weight_delta = settled_weight - pre_pulse_weight;

            LOG_BLE("AutoTune: Priming weight delta = %.3fg (threshold: %.3fg)\n",
                    weight_delta, GRIND_AUTOTUNE_WEIGHT_THRESHOLD_G);

            if (weight_delta <= GRIND_AUTOTUNE_WEIGHT_THRESHOLD_G) {
                LOG_BLE("ERROR: Priming failed - no weight increase detected\n");
                log_message("\nPrime failed");
                log_message("Check:");
                log_message("- Beans loaded");
                log_message("- Power on");
                log_message("- Cup placed");
                complete_with_failure("Priming failed - no grounds detected");
                return;
            }

            // Priming successful, now tare
            LOG_BLE("AutoTune: Priming complete (%.3fg added), taring scale\n", weight_delta);
            start_tare();
            break;
        }

        case AutoTuneSubPhase::TARING:
            update_tare();
            break;
    }
}
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

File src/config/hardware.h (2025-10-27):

#pragma once

//==============================================================================
// HARDWARE CONFIGURATION CONSTANTS
//==============================================================================
// This file contains hardware-specific configuration values that define the
// physical characteristics and constraints of the ESP32-S3 coffee grinder system.
// These values are tied to the specific hardware implementation and should only
// be modified when changing hardware components.

//------------------------------------------------------------------------------
// GPIO PIN ASSIGNMENTS
//------------------------------------------------------------------------------
// Touch Controller (I2C)
#define HW_TOUCH_I2C_SDA_PIN 47                                                // I2C data pin for capacitive touch controller
#define HW_TOUCH_I2C_SCL_PIN 48                                                // I2C clock pin for capacitive touch controller
#define HW_TOUCH_I2C_ADDRESS 0x38                                              // I2C address of FT3168 touch controller

// Display Controller (QSPI)
#define HW_DISPLAY_CS_PIN 9                                                    // SPI chip select for display controller
#define HW_DISPLAY_SCK_PIN 10                                                  // SPI clock for display controller
#define HW_DISPLAY_D0_PIN 11                                                   // SPI data line 0 (QSPI mode)
#define HW_DISPLAY_D1_PIN 12                                                   // SPI data line 1 (QSPI mode)
#define HW_DISPLAY_D2_PIN 13                                                   // SPI data line 2 (QSPI mode)
#define HW_DISPLAY_D3_PIN 14                                                   // SPI data line 3 (QSPI mode)
#define HW_DISPLAY_RESET_PIN 21                                                // Display reset pin

// Load Cell ADC Pins
#define HW_LOADCELL_DOUT_PIN 3                                                 // HX711 data output pin
#define HW_LOADCELL_SCK_PIN 2                                                  // HX711 serial clock pin

// Motor Control
#define HW_MOTOR_RELAY_PIN 18                                                  // GPIO pin for grinder motor control relay
#define HW_GRINDER_SETTLING_TIME_MS 500                                        // Startup transient immunity (tune based on mechanical rigidity, 0 to disable)

//------------------------------------------------------------------------------
// LOAD CELL ADC SPECIFICATIONS
//------------------------------------------------------------------------------
// Sample rate configuration
#define HW_LOADCELL_SAMPLE_RATE_SPS 10                                         // Current sample rate setting
#define HW_LOADCELL_SAMPLE_INTERVAL_MS (1000 / HW_LOADCELL_SAMPLE_RATE_SPS)   // Calculated sample interval

// Calibration validation
#define HW_LOADCELL_CAL_MIN_ADC_VALUE 1000                                    // Minimum ADC value to confirm weight placed on scale

//------------------------------------------------------------------------------
// DISPLAY SPECIFICATIONS  
//------------------------------------------------------------------------------
#define HW_DISPLAY_WIDTH_PX 280                                                // LCD width in pixels
#define HW_DISPLAY_HEIGHT_PX 456                                               // LCD height in pixels
#define HW_DISPLAY_OFFSET_X_PX 0                                               // X offset for display positioning
#define HW_DISPLAY_ROTATION_DEG 0                                              // Display rotation angle
#define HW_DISPLAY_IPS_INVERT_X 180                                            // IPS X-axis inversion setting
#define HW_DISPLAY_IPS_INVERT_Y 24                                             // IPS Y-axis inversion setting
#define HW_DISPLAY_COLOR_ORDER 20                                              // Color channel ordering
#define HW_DISPLAY_MINIMAL_BRIGHTNESS_PERCENT 15                               // Minimum brightness percentage (to avoid too dim to see)

//------------------------------------------------------------------------------
// SERIAL COMMUNICATION
//------------------------------------------------------------------------------
#define HW_SERIAL_BAUD_RATE 115200                                             // UART baud rate for debug/logging output

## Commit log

2025-09-15 feat: Initial release of smart-grind-by-weight ESP32-S3 coffee grinder
    Complete ESP32-S3 intelligent coffee scale with grind-by-weight functionality.
    Features predictive grinding system, LVGL touch UI, and BLE OTA updates.
    Automatically grinds coffee beans to precise target weights using flow
    prediction and pulse correction algorithms.
    Key Features:
    - 8-phase state machine with predictive flow control
    - 10 pulse corrections for precision grinding
    - LVGL touchscreen interface with 7 screens
    - Multi-mode precision weight measurement (HX711)
    - BLE OTA updates and data streaming
    - Comprehensive grind session logging and analysis
    - 4-layer architecture (Hardware/Control/System/UI)
    Hardware:
    - E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
    [Back plate.stl, Cover.stl, Cup holder hole cover.stl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]
2025-09-15 UI/Prefs: fix Preferences handle misuse and debounced brightness persistence
    - Use local Preferences for brightness reads/writes to avoid switching/closing the shared "grinder" handle
    - Persist brightness only on slider release (normal + screensaver); keep live preview on move
    - Initialize sliders from "brightness" namespace (not "grinder")
    - Add reset-reason logging at startup for diagnosing resets/freezes
    [main.cpp]
2025-09-15 feat: Add negative weight failsafe to grind controller
    Add failsafe that triggers timeout screen when weight goes below -1.0g during active grinding phases (after TARE_CONFIRM). This prevents unsafe operation if scale detects unexpectedly negative readings.
    [grind_controller.cpp]
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2025-09-17 fix: Resolve build failures on clean environments (fixes #1)
    Convert from mixed ESP-IDF/Arduino hybrid to pure Arduino framework:
    ## RMT Implementation
    - Replace ESP-IDF RMT API with Arduino HAL RMT API
    - Remove: driver/rmt_tx.h, driver/rmt_encoder.h includes
    - Remove: rmt_channel_handle_t, rmt_encoder_handle_t types
    - Add: esp32-hal-rmt.h with rmtInit(), rmtWriteLooping(), rmtWrite()
    - Maintain same grinder control functionality with correct HAL
    ## Watchdog API
    - Update ESP-IDF v4.x watchdog API to v5.x structure-based API
    - Replace: esp_task_wdt_init(timeout, panic)
    - With: esp_task_wdt_init(&wdt_config) using esp_task_wdt_config_t
    ## C++ Standard & Dependencies
    - Upgrade C++ standard f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
    [ota_handler.cpp]
2025-09-17 fix: Correct platformio.ini to resolve the right platform
    Fixes platformio.ini configuration to ensure the correct pioarduino
    platform is resolved consistently across all development environments.
    ## Platform Configuration
    - Explicitly declare pioarduino platform (was causing resolution issues)
    - Use Git version of Arduino_GFX library for proper compatibility
    - Remove explicit framework version pinning (let pioarduino control versions)
    - Remove C++ standard override (handled by pioarduino platform)
    ## Documentation & Troubleshooting
    - Add comprehensive troubleshooting guide for Windows development setup
    - Document pioarduino platform usage in build instructions
    ## Bug Fixes
    - Fix format s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
2025-09-17 fix: Revert unnecessary RMT and watchdog API changes
    Restore ESP-IDF RMT implementation and fix OTA watchdog configuration:
    ## RMT Revert
    - Restore proper ESP-IDF RMT with hardware-managed infinite loops
    - Revert from Arduino HAL back to rmt_channel_handle_t/rmt_encoder_handle_t
    - Fix pulse completion detection (was always returning true)
    - Restore non-blocking hardware-managed operations
    ## OTA Watchdog Fix
    - Remove invalid #include inside start_ota() function
    - Restore esp_task_wdt_reconfigure() (was using incorrect init/deinit)
    - Fix struct initialization syntax
    ## Build System
    - Remove unnecessary -std=gnu++17 flag
    - Keep platform pinning (the actual fix that resolved build issues)
    R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
    [ota_handler.cpp]
2025-09-17 fix: Remove deprecated BLE2902 descriptors and volatile increment warnings
    - Remove manual BLE2902 descriptor additions since NimBLE automatically adds them for notify characteristics
    - Fix volatile increment warning by using explicit assignment instead of ++ operator
    [grind_controller.cpp]
2025-09-17 fix: Resolve BLE data export timeout due to race condition
    Fixed race condition where ESP32 responded to GET_FILE_LIST command faster
    than Python client could set up reception state, causing timeout errors.
    Changes:
    - ESP32: Add 100ms delay between data transmission and status notification
    - Python: Set up reception state before sending BLE commands
    - Python: Add small delay to ensure proper state initialization
    Resolves data export failures since commit 8800207.
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2025-09-21 feat: Adjust 3D printed parts for T70 load cell compatibility
    - Updated cup holder and backplate fit to accommodate T70 load cells
    - Reinforced load cell mounting areas with stress-relieving fillets in corners
    - Updated documentation with T70 compatibility notices in README.md and DOC.md
    - Updated 2 STL files: Cup holder.stl and Back plate.stl
    - All T70 users must use latest 3D files for proper fit
    [Back plate.stl, Cup holder.stl]
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2025-09-22 feat: Change grind completion accuracy for better user experience
    Change grind completion logic from <= to < tolerance threshold to avoid
    displaying confusing target misses. Previously, achieving exactly 0.05g
    error would still complete the grind, showing weights like 17.9g or 18.1g
    for an 18.0g target, which appeared inaccurate to users despite being
    within tolerance. Now only completes when error is strictly less than
    tolerance, ensuring displayed weights better match user expectations.
    [grind_controller.cpp]
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2025-09-26 Fix strategy accessors and ensure build passes
    [weight_grind_strategy.cpp]
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2025-09-26 Reimplement mock HX711 driver with smoother flow and noise
    [WeightSensor.cpp, mock_hx711_driver.cpp]
2025-09-27 Add time mode additional pulse functionality
    - Add TIME_ADDITIONAL_PULSE grind phase for post-completion pulses
    - Implement split-button UI layout (OK + PULSE) in time mode completion
    - Add pulse button management with auto-disable during pulse operation
    - Integrate 100ms configurable pulse duration with mock HX711 support
    - Add 60-second auto-return timer reset on each pulse
    - Preserve chart data during pulse operations to prevent clearing
    - Update documentation with concise pulse button description
    [grind_controller.cpp, user_config.h]
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2025-09-28 feat: Add persistent grind mode storage across reboots
    - Add grind mode storage to ProfileController preferences
    - Load saved grind mode on startup, defaulting to WEIGHT if unset
    - Save grind mode automatically when toggled in UI
    - Remove hardcoded WEIGHT mode initialization in UIManager
    [user_config.h]
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2025-09-28 Standardize configuration includes to use constants.h
    Replaced direct config file includes with constants.h across the codebase
    to centralize configuration access and improve maintainability.
    - Removed 73 direct config includes from 53 files
    - All files now use constants.h as single entry point for configuration
    - Maintains clean separation with existing prefixing (USER_, HW_, SYS_, etc.)
    - Preserves necessary exceptions for circular dependencies in Bluetooth module
    - Build verified successful (build #2444)
    [WeightSensor.cpp, circular_buffer_math.cpp, grind_controller.cpp]
2025-09-28 Refactor: Complete config folder reorganization and unused parameter cleanup
    Major reorganization of configuration system with comprehensive cleanup:
    ### Config Folder Restructuring
    - Replace fragmented config files with domain-organized structure
    - bluetooth.h: All BLE service UUIDs, timeouts, and power settings
    - hardware.h: GPIO pins, display specs, serial communication
    - theme.h: UI colors, dimensions, and styling constants
    - debug.h: Mock hardware, debug flags, performance monitoring
    - grind_control.h: Pulse mappings, flow parameters, timeouts
    - system_config.h: FreeRTOS tasks, timeouts, algorithm parameters
    - user_config.h: Coffee profiles, calibration, screen settings
    - constants.h: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
    [bluetooth.h, circular_buffer_math.cpp, debug.h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]
2025-09-28 feat: Add production-safe build targets with mock hardware environment
    - Add waveshare-esp32s3-touch-amoled-164-mock build environment
    - Default debug.h to production-safe settings (mock disabled)
    - Enable mock hardware and visual indicators only via build flags
    - Prevents accidental production builds with debug settings enabled
    [debug.h]
2025-09-29 fix: Resolve compiler warnings for format specifiers and unused variables
    - Fix uint32_t format specifier in HX711Driver::conversion_24bit()
    - Fix float format specifier in WeightGrindStrategy::run_predictive_phase()
    - Fix partition address format specifiers in OTAHandler::finalize_update()
    - Remove unused variable warning in ReadyScreen::create_profile_page()
    [hx711_driver.cpp, ota_handler.cpp, weight_grind_strategy.cpp]
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2025-09-29 fix: Prevent -0.0g display by clamping near-zero weights to 0.0
    Clamps weights between -0.05g and 0.05g to exactly 0.0g in get_display_weight()
    to eliminate floating-point precision artifacts that cause confusing -0.0g display
    on arc and chart screens.
    [WeightSensor.cpp]
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2025-09-29 fix: Reset timeout timer when starting additional pulses in time mode
    Prevents timeout when user waits long time after grind completion
    before adding additional pulses. The 30-second timeout now resets
    when starting each additional pulse.
    [grind_controller.cpp]
2025-09-29 feat: Add browser-based firmware flashing tool
    - Web flasher with USB (ESP Web Tools) and BLE OTA support
    - Two-tier approach: USB for initial setup, BLE for updates
    - Chrome/Edge browser support with Web Serial and Web Bluetooth APIs
    - Automatic firmware selection and progress tracking
    - Deploys only on releases (not every push) to avoid unnecessary deployments
    - Release workflow builds firmware and updates web-flasher, then deploys
    - Updated documentation with web flasher instructions
    [bluetooth.h]
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2025-10-02 refactor: decompose UIManager into feature-focused controllers
    Replace monolithic 1000+ line UIManager with specialized controllers.
    Each UI feature now lives in a single controller that owns its event
    handling, business logic, and view updates.
    Benefits:
    - Less indirection: new features touch one controller instead of 4-5 files
    - Better maintainability: related functionality grouped by domain
    - Simpler to understand: focused components with clear responsibilities
    - Preserved existing LVGL screen architecture and functionality
    Controllers added:
    - ReadyUIController: profile tab navigation, long-press editing, swipe mode switching
    - EditUIController: target value editing with save/cancel, p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
    [main.cpp]
2025-10-02 fix: enhance BLE OTA protocol for build number and firmware version support
    - Fix Python BLE flasher build number detection by checking both include/ and src/config/ paths for git_info.h
    - Extend BLE OTA protocol to support firmware version in addition to build numbers (backwards compatible)
    - Update web flasher to send actual firmware version instead of generating fake build numbers
    - Improve OTA failure screen to display proper expected vs current build/version information
    - Add comprehensive version checking in OTA verification process
    This enables both local development builds (with incrementing build numbers) and web flasher
    releases (with semantic version strings) to work correctly wi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
    [ota_handler.cpp]
2025-10-02 feat: add load cell noise diagnostics to system info
    Remove smooth reading display and add standard deviation metrics for sensor noise analysis. Shows both gram and ADC unit standard deviations with 4-decimal precision to help diagnose tare settling issues.
    [WeightSensor.cpp]
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2025-10-02 feat: add noise floor threshold indicator and fix negative std dev bug
    - Add "Noise Floor" section label for standard deviation values
    - Add "Under threshold: Yes/No" indicator with red color for failures
    - Move uptime and RAM to bottom of info page for better organization
    - Reduce std dev update rate to 1 second with 1000ms window for stable readings
    - Fix negative std dev bug when cal_factor is negative (use abs value)
    - Improve diagnostic clarity for users troubleshooting tare settling issues
    [WeightSensor.cpp]
2025-10-02 fix: be more forgiving and allow for more load cell noise
    [grind_control.h]
2025-10-02 feat: add noise level diagnostic to prevent slow taring
    Replace basic threshold check with sustained noise detection that shows "Noise level: OK / Too High". Only flags hardware issues causing taring >3 seconds, filtering out normal motor/electrical interference.
    [WeightSensor.cpp]
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2025-10-04 feat(diagnostics): add DiagnosticsController and mechanical-instability detection; surface warnings in UI • Introduce DiagnosticsController (state machine, persistence, hysteresis, prioritization) as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
    [WeightSensor.cpp, grind_control.h, grind_controller.cpp]
2025-10-04 fix(ota): fix web flasher OTA failure detection
    Two issues prevented the OTA_FAILED screen from showing after interrupted web
    flasher updates:
    1. NVS key 'new_firmware_ver' (16 chars) exceeded ESP32's 15-char limit,
    causing silent storage failure. Changed to 'new_fw_ver' (10 chars).
    2. Verification logic checked build number before firmware version. Web flasher
    sends dummy build #1, which always passed (current >= 1), so firmware
    version was never checked. Fixed by prioritizing firmware version check
    when available (web flasher), falling back to build number only when no
    version is sent (Python flasher).
    Python flasher unaffected - uses shorter 'new_build_nr' key and no ver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
    [ota_handler.cpp]
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2025-10-05 feat(calibration): prevent calibration without weight on scale
    Calibration now validates that weight has been placed on the scale before allowing the user to proceed. The OK button remains hidden until the load cell detects a change in ADC reading above the minimum threshold, ensuring calibration accuracy.
    [WeightSensor.cpp, hardware.h]
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2025-10-07 Fix: Reconfiguring task watchdog timer to 600s (up from 300s) for users with slow BLE transfer rates
    [ota_handler.cpp]
2025-10-08 fix(ota): Prevent watchdog timeout during OTA updates
    Suspends non-essential tasks during the OTA process to prevent the watchdog timer from expiring due to slow transfer speeds.
    The following changes have been made:
    - Increased the task watchdog timeout to 600s during OTA.
    - Suspended the WeightSampling, GrindControl, and FileIO tasks at the start of the OTA process.
    - Ensured that the suspended tasks are resumed if the OTA process fails or is aborted.
    [ota_handler.cpp]
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2025-10-09 fix(statistics): Fix device uptime tracking and display
    - Fix uptime accumulation logic to properly update all pending minutes instead of losing accumulated time
    - Display uptime in hours and minutes format (Xh Ym) instead of hours only
    [main.cpp]
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2025-10-10 refactor: Rename flow rate methods and constants for clarity
    Renamed `get_effective_flow_rate()` to `get_clamped_pulse_flow_rate()` and `GRIND_FLOW_RATE_REFERENCE_GPS` to `GRIND_PULSE_FLOW_RATE_FALLBACK_GPS` to better reflect their purpose: clamping measured pulse flow rates to sane bounds and providing a fallback value when measurements are invalid or too low.
    [grind_control.h, weight_grind_strategy.cpp]
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2025-10-10 feat: Add motor response latency auto-tuning feature
    Implement automatic calibration of minimum motor pulse duration to account
    for hardware variations across different grinders, voltages, and relay types.
    Features:
    - 3-phase binary search algorithm with statistical verification
    - Runtime-configurable motor latency (default 75ms, range 30-150ms)
    - NVS persistence with automatic loading on boot
    - Full UI integration with progress display and success/failure screens
    - Settings → Tools → "Auto-Tune Motor Response" button
    - Settings → Diagnostics → "Motor Latency" display
    - New AUTOTUNING UI state with dedicated screen and controller
    Algorithm:
    - Phase 0: Chute priming (500ms pulse + t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
    [autotune_controller.cpp, grind_control.h, grind_controller.cpp]
2025-10-10 feat(mock): Add motor latency threshold to pulse simulation
    Enhance mock HX711 driver to better simulate real motor behavior by adding
    a minimum pulse duration threshold below which no grounds are produced.
    - Add DEBUG_MOCK_MOTOR_LATENCY_MS constant (45ms hidden threshold)
    - Check pulse duration against threshold in handle_pulse_request()
    - Only produce grounds if pulse >= motor latency threshold
    - Pulses shorter than threshold produce zero mass (no grounds)
    This allows realistic testing of the auto-tune algorithm, which should
    discover the 45ms threshold through binary search and verification.
    Build: 2996
    Co-Aut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
    [debug.h, mock_hx711_driver.cpp]
2025-10-10 refactor(autotune): Convert to non-blocking state machine architecture
    Refactor AutoTuneController to use proper non-blocking execution pattern
    matching GrindController architecture, eliminating blocking while loops
    and delay() calls.
    **Key Changes:**
    - Add AutoTuneSubPhase enum (IDLE, PULSE_EXECUTE, MOTOR_SETTLING, SCALE_SETTLING, MEASURE_COMPLETE, TARING)
    - Replace blocking methods with non-blocking state machines (update_priming_phase, update_binary_search_phase, update_verification_phase)
    - Add sub-phase execution methods matching GrindController pattern (start_pulse, update_pulse_execute, update_motor_settling, update_scale_settling)
    - Add phase transition helpers (switch_phase, switch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
    [autotune_controller.cpp]
2025-10-10 Fix autotune UI completion handling
    [autotune_controller.cpp]
2025-10-10 fix: Use valid NVS key length for motor latency persistence
    Fixed autotune motor latency not persisting across reboots. The NVS key "grind.motor_latency_ms" (23 chars) exceeded ESP32's 15-character limit, causing silent write failures. Changed to "motor_lat_ms" (13 chars) and added error checking.
    [grind_controller.cpp]
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2025-10-10 fix: Correct pulse duration calculation to properly account for motor latency
    Motor latency is the base startup time required before any productive
    grinding occurs. The pulse duration should be:
    pulse_duration = motor_latency + productive_grinding_time
    Previously, the calculation incorrectly treated motor latency as a minimum
    bound rather than a required base component, leading to incorrect pulse
    durations.
    Also updated default motor latency from 75ms to 50ms and increased max
    productive duration from 225ms to 250ms.
    [grind_control.h, weight_grind_strategy.cpp]
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2025-10-10 refactor: Redesign autotune screen as console-style interface
    Replace the static progress screen with a scrolling console log that
    provides real-time feedback on the autotune process.
    - Add console message system to autotune controller with log_message()
    - Generate timestamped log messages at each phase transition
    - Replace custom confirmation screen with standard ConfirmScreen component
    - Remove duplicate confirmation (was showing two confirmations)
    - Implement scrolling textarea for console output in autotune screen
    - Update confirmation message to be more concise (removed "Grinder on")
    - Simplify to single confirmation flow: Settings → Console → Result
    Console output format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
    [autotune_controller.cpp]
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2025-10-12 Fix: Add settling safety gate to autostart trigger
    Prevents false autostart triggers from scale bumps or quick cup placement/removal by requiring both sustained weight change and settled state.
    - Extended window check: 3000ms (1000ms settling + 2000ms trigger)
    - Requires weight delta ≥50g over extended window AND currently settled
    - Optimized: Check cheap is_settled() before expensive 3000ms delta calc
    - Removed unused debug logging code
    [user.h]
2025-10-12 feat: Add comprehensive BLE diagnostic report system
    Implement complete diagnostic reporting system for troubleshooting GitHub issues. Report includes firmware info, system stats, all compile-time constants, and lifetime statistics.
    Firmware:
    - Add BLE_SYSINFO_DIAGNOSTICS_CHAR_UUID for report trigger
    - Implement generate_diagnostic_report() with memory-safe streaming (512-byte chunks)
    - Report includes 11 sections with 98+ diagnostic data points:
    - Firmware version, build #, git commit, timestamp
    - System runtime (uptime, CPU, RAM, flash, driver type)
    - 48 grind control constants (all algorithm parameters)
    - 11 user config constants (profiles, limits, timeouts, auto-actions)
    - Lif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
    [bluetooth.h]
2025-10-12 feat: Add autotune log file streaming to LittleFS
    Autotune console output now streams to /autotune.log on the filesystem partition. Log file is created at start (overwrites previous), messages written during tuning with immediate flush, and closed with completion summary. Preserves diagnostic data even if device crashes during tuning.
    [autotune_controller.cpp]
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2025-10-16 feat: Improve auto-tune reliability with longer prime and weight verification
    Increased priming pulse from 500ms to 1s for more reliable chute priming and added weight verification to detect setup issues early. Auto-tune now fails fast with helpful error message if no grounds detected during priming phase.
    [autotune_controller.cpp, grind_control.h]
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2025-10-16 fix: Display all autotune test results on screen
    Adds RESULT_LOGGED sub-phase to ensure UI displays each test result message
    before logging completion messages. Previously, the final test result was
    overwritten by the 'Found' message when both were logged in the same cycle.
    [autotune_controller.cpp]
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2025-10-27 feat: Add motor settling gate to prevent startup transient false positives
    Motor startup vibrations can cause brief positive/negative weight spikes that trigger premature predictive phase stops or false negative weight failsafes. This adds configurable 500ms settling immunity after motor start to ignore transients while still catching real failures.
    Particularly helpful for less rigid mechanical designs (3D printed housings with flex/play) but tunable based on system characteristics.
    [grind_controller.cpp, hardware.h, weight_grind_strategy.cpp]
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2025-10-31 fix(ble-ota): prevent OTA suspend panic
    [ota_handler.cpp]
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2025-10-31 fix(ota): optimize partition erase to prevent 20-second upload delay (#52)
    Changed partition erase chunk size from 4KB to 256KB in delta_partition_init().
    The recent watchdog handling commit (cbc4694) introduced chunked erasing with
    taskYIELD() every 4KB (SPI_FLASH_SEC_SIZE), causing ~384 context switches for
    a 1.5MB file. This resulted in a 20-second delay before OTA upload could start.
    With 256KB chunks, a 1.5MB file now only requires ~6 yields instead of 384,
    dramatically reducing the delay while still maintaining watchdog protection.
    [ota_handler.cpp]
2026-04-19 Fix BLE crashes: toggle crash, report generation, and mid-report disconnect #111
    [system.h]
2026-04-20 OTA fix for failed OTA update if fw versions mismatch + corner case fix for OTA
    [main.cpp, ota_handler.cpp]
